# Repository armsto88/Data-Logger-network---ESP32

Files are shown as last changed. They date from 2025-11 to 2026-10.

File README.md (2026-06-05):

# ESP32 Sensor Network � Mothership + Nodes

An **ESP-NOW**�based environmental sensor network: field-deployed nodes collect data, a mothership hub aggregates and logs it, and an optional LTE backhaul uploads to the cloud.

---

## Repository Structure

```
mothership/           Mothership hub (ESP32-WROOM)
  docs/                 Power, wake, LTE, PCB design notes
  firmware/src/         Production firmware (main, BLE, ESP-NOW, SD, RTC)

node/                 Sensor nodes (ESP32-WROOM)
  docs/                 Hardware, sensors, ultrasonic design notes
  firmware/
    src/                Production firmware (main, drivers, sensors, storage, time)
    shared/             Shared protocol headers (protocol.h, sensors.h)
    tests/              Bring-up and validation sketches

docs/                 Shared/cross-system documentation
  concept_overview.md   System architecture and ESP-NOW messaging
  FIRMWARE_AND_HARDWARE_NOTES.md  Integration notes
  NATIVE_APP_*.md       App integration and data schemas
  MULTI_NODE_VALIDATION_*.md  Deployment validation
  archive/              Manuscript drafts and reference files

hardware/             PCB, CAD, simulation, and manufacturing assets
  ultrasonic_anemometer/  Ultrasonic wind sensor subproject

platformio.ini       Build configuration (all targets)
CONTRIBUTING.md      Repo organization and contribution rules
```

---

## Quick Links

- **Mothership docs:** [mothership/docs/README.md](mothership/docs/README.md)
- **Node docs:** [node/docs/README.md](node/docs/README.md)
- **Shared docs index:** [docs/README.md](docs/README.md)
- **Contribution guide:** [CONTRIBUTING.md](CONTRIBUTING.md)

---

## System Overview

### Mothership (ESP32-WROOM)

- Runs a Wi-Fi access point with a web UI dashboard
- Receives sensor data from nodes via ESP-NOW
- Logs all data to CSV on a microSD card
- Keeps time via a DS3231 RTC (the network time authority)
- Manages node discovery, pairing, deployment, and scheduling
- Power-gated design: DS3231 alarm or config button wakes the board; ESP32 latches power via `PWR_HOLD`
- Two power domains: `KEEP_ALIVE` (always-on, RTC + config latch) and `3V3_SYS` (switched, ESP32 + SD + logic)
- Optional LTE backhaul via SIMCom A7670G modem (UART2 + level shifters)
- CH340C USB-UART for programming and serial console

### Sensor Nodes (ESP32-WROOM)

- Sleep between measurement intervals (DS3231 Alarm 1 + FET power gate)
- Environmental sensors: SHT40 (temp/humidity), AS7343 (light spectrum), ADS1015 (soil probes)
- Ultrasonic anemometer subsystem: 40 kHz transducers, MT3608 22 V boost, TC4427 driver, TLV9062IDR RX amplifier
- I2C sensor mux via PCA9548A
- Transmit readings to the mothership via ESP-NOW
- Automatically request time sync when needed
- Resume operation after power cuts (NVS state + RTC coin cell)
- RUN/KILL hard switch for full power cut

### Communication

- **Data:** node -> mothership (`SENSOR_DATA` packets)
- **Control:** mothership -> node (`PAIR_NODE`, `DEPLOY_NODE`, `SET_SCHEDULE`, `UNPAIR_NODE`, `TIME_SYNC`)
- **Discovery:** nodes broadcast `DISCOVER_REQUEST`; mothership responds

---

## Building

The root `platformio.ini` defines all build targets. Build from the repo root:

```bash
# Mothership
pio run -e esp32s3

# Node main systems bring-up
pio run -e esp32wroom-v2-main-systems

# Individual bring-up tests
pio run -e esp32wroom-i2c-scan
pio run -e esp32wroom-ds3231-alarm-10s
pio run -e esp32wroom-sht40-as7343-mux
# ... see platformio.ini for all environments
```

---

## Key Design Documents

| Document | Location | Description |
|---|---|---|
| Power & Wake Architecture | [mothership/docs/MOTHERSHIP_POWER_AND_WAKE_DESIGN_NOTE.md](mothership/docs/MOTHERSHIP_POWER_AND_WAKE_DESIGN_NOTE.md) | Power gating, RTC wake, pin allocation |
| PCB Schematic Review | [mothership/docs/MOTHERSHIP_PCB_SCHEMATIC_REVIEW_2026-06-05.md](mothership/docs/MOTHERSHIP_PCB_SCHEMATIC_REVIEW_2026-06-05.md) | Consolidated pre-order review with critical checks |
| LTE Backhaul Concept | [mothership/docs/MOTHERSHIP_LTE_BACKHAUL_CONCEPT.md](mothership/docs/MOTHERSHIP_LTE_BACKHAUL_CONCEPT.md) | A7670G modem integration and upload workflow |
| Node Hardware Checklist | [node/docs/NODE_HARDWARE_V2_CHECKLIST.md](node/docs/NODE_HARDWARE_V2_CHECKLIST.md) | V2 hardware bring-up and validation |
| Node PCB Overview | [node/docs/NODE-PCB-OVERVIEW.md](node/docs/NODE-PCB-OVERVIEW.md) | Node PCB design summary and pin mapping |
| Local Storage Contract | [node/docs/NODE-LOCAL-STORAGE-CONTRACT-V1.md](node/docs/NODE-LOCAL-STORAGE-CONTRACT-V1.md) | Queue storage and data format specification |
| Concept Overview | [docs/concept_overview.md](docs/concept_overview.md) | High-level system architecture |

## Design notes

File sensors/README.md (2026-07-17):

# Sensor Calibration & Validation Documentation

This directory contains peer-review frameworks and calibration protocols for the FieldMesh data logger sensors, grounded in scientific literature on sensor accuracy, precision, and field validation.

## Documents

### 1. [CALIBRATION_VALIDATION_SCIENTIFIC_FOUNDATION.md](CALIBRATION_VALIDATION_SCIENTIFIC_FOUNDATION.md)
**Start here.** A survey of scientific principles for sensor calibration and validation.

**Covers:**
- Pre-deployment vs. post-deployment calibration strategies
- Accuracy vs. precision definitions
- Environmental sensor inter-comparison methods
- Sensor drift drivers (temperature, humidity, UV, chemistry, stress)
- In-situ recalibration algorithms for sensor networks
- Data quality & outlier detection
- Peer review checklist

**Key insight:** Laboratory calibration alone is insufficient. Field validation against reference standards is essential.

---

### 2. [SOIL_MOISTURE_CALIBRATION_PROTOCOL.md](SOIL_MOISTURE_CALIBRATION_PROTOCOL.md)
**For soil moisture sensors** (ADS1115 + capacitive probes).

**Phases:**
1. **Pre-deployment (lab):** Dry-down calibration curves for site-representative soil samples
2. **Field site survey:** Soil texture/density characterization; matching to lab curves
3. **On-site field calibration:** Gravimetric validation or reference sensor cross-check
4. **Drift monitoring:** Monthly checks; outlier filtering; temperature correction
5. **Publication:** Quality claims + supporting data

**Expected accuracy:** ±0.03–0.05 m³/m³ (3–5% VWC) with proper field calibration.

**Key finding from literature:** Field-calibrated sensors achieve **50% better accuracy** than lab-only calibration.

---

### 3. [SPECTRAL_SENSOR_CALIBRATION_PROTOCOL.md](as7341/SPECTRAL_SENSOR_CALIBRATION_PROTOCOL.md)
**For the AS7341 spectral sensor** (8 visible bands + Clear + NIR).

**Phases:**
1. **Dark current baseline:** Offset calibration across all 11 gain settings
2. **Linearity validation:** Test ADC response across full intensity range
3. **Gain validation:** Verify auto-gain algorithm maintains consistency
4. **Spectral response:** Color accuracy and cross-channel crosstalk
5. **Field deployment:** PAR proxy validation against calibrated reference
6. **Thermal stability:** Temperature coefficient measurement & correction
7. **Snapshot validation:** Rules for flagging saturated/invalid/low-signal data
8. **Multi-node cross-check:** Consistency across deployed units

**Expected accuracy:** PAR estimates ±100 µmol m⁻² s⁻¹ (R² >0.85 vs. reference meter).

---

## How to Use These Documents

### For Initial Deployment
1. Read **CALIBRATION_VALIDATION_SCIENTIFIC_FOUNDATION.md** (20 min)
2. Follow the appropriate sensor protocol:
   - Soil sensors → **SOIL_MOISTURE_CALIBRATION_PROTOCOL.md**
   - Spectral sensor → **SPECTRAL_SENSOR_CALIBRATION_PROTOCOL.md**
3. Use the **peer review checklists** at the end of each protocol

### For Data Quality Assurance
- Reference the **drift monitoring** and **outlier detection** sections during deployment
- Compare observed sensor behavior against expected performance ranges documented
- Re-calibrate if drift exceeds thresholds (typically 5% per 30 days)

### For Publishing or Sharing Data
- Fill in the **data reporting template** from the protocol you used
- Cite the scientific papers listed (links provided)
- Attach calibration curves, validation plots, and raw metadata

---

## Scientific Foundation & References

All protocols are based on peer-reviewed literature:

### General Calibration
- [Sensor Calibration Overview (ScienceDirect Topics)](https://www.sciencedirect.com/topics/earth-and-planetary-sciences/sensor-calibration)
- [Framework for Simulation of Sensor Networks — In Situ Calibration Algorithms (PMC)](https://pmc.ncbi.nlm.nih.gov/articles/PMC7472635/)
- [Self-Calibration Methods for Uncontrolled Environments (arXiv)](https://arxiv.org/pdf/1905.11060)

### Environmental Sensor Accuracy
- [EPA: Precision and Accuracy Study](https://www.epa.gov/sites/default/files/2014-08/documents/precisionandaccuracy.pdf)
- [Challenges and Opportunities in Calibrating Low-Cost Environmental Sensors (PMC)](https://pmc.ncbi.nlm.nih.gov/articles/PMC11175279/)
- [Low-Cost Aerosol Sensor Inter-comparison (PMC)](https://pmc.ncbi.nlm.nih.gov/articles/PMC5580827/)
- [Electrical Conductivity Sensor Accuracy Study (PMC)](https://pmc.ncbi.nlm.nih.gov/articles/PMC10159144/)

### Soil Moisture Sensors
- [Calibration and Field Validation of Smart Soil Moisture Monitoring (Harvard ADS)](https://ui.adsabs.harvard.edu/abs/2023EGUGA..2511699Y/abstract)
- [Laboratory Calibration and Field Validation — 5TE Sensor (PMC)](https://www.ncbi.nlm.nih.gov/pmc/articles/PMC6928628/)
- [Designing and Field Calibration of Low-Cost Microcontroller-Based Sensors (Nature Scientific Reports)](https://www.nature.com/articles/s41598-024-81288-z)
- [Low-Cost Capacitive Soil Moisture Sensors for Irrigation (MDPI)](https://www.mdpi.com/1424-8220/25/2/343)
- [Calibration and Validation of Soil Water Reflectometers (Wiley)](https://acsess.onlinelibrary.wiley.com/doi/full/10.1002/vzj2.20190)

### Spectral/Optical Sensors
- [Dynamic Validation of Calibration Accuracy — Multi-Sensor Systems (PMC)](https://pmc.ncbi.nlm.nih.gov/articles/PMC11207938/)

### Environmental Drift
- [Environmental Stressors Causing Calibration Drift (Clarity.io Blog)](https://www.clarity.io/blog/which-environmental-stressors-most-often-trigger-calibration-drift-and-necessitate-shorter-calibration-intervals)

---

## Quick Reference: Calibration Timeline

| When | Action | Sensor Type | Evidence |
|---|---|---|---|
| **Before deployment** | Lab dry-down calibration | Soil | Calibration curve + R² |
| **Field site prep** | Soil characterization | Soil | Texture, bulk density, organic matter |
| **Week 1–2** | Baseline reference check | All | First gravimetric / reference measurement |
| **Weekly** | Auto-validation | Spectral | PAR proxy vs. reference meter (if available) |
| **Monthly** | Drift assessment | All | Re-measure reference samples or co-located sensor |
| **Quarterly** | Re-calibrate if drift >5% | All | Update coefficients; recapture baseline |
| **End of season** | Final accuracy report | All | Compare all readings to reference; summarize performance |

---

## Compliance & Quality Flags

Every sensor reading should be assigned a **quality flag**:

```
[VALID]              — all checks passed, use with confidence
[UNVALIDATED]        — not yet checked against reference, provisional
[DRIFT_WARNING]      — drift detected but <10%; monitor closely
[OUT_OF_RANGE]       — value physically impossible; reject
[SATURATED]          — sensor maxed out (especially spectral); data unreliable
[LOW_SIGNAL]         — noise-dominated; low confidence
[RECALIBRATED]       — fresh calibration applied; baseline reset
[REFERENCE_MISMATCH] — doesn't match reference sensor; investigate
```

Include these flags in your data export so downstream analysis knows data provenance.

---

## Next Steps

1. **Soil moisture:** Complete Phase 1 (lab calibration) before field deployment. Plan Phase 3 (field validation) for first 2 weeks on site.

2. **Spectral sensor:** Phase 1–2 can happen in a lab or bright room. Phase 5 (field validation) requires 1–2 weeks of co-location with a PAR meter (borrow one if needed).

3. **Air temperature/humidity (SHT41):** Low-cost, already factory-calibrated to ±2–3%. Skip extensive re-calibration; just verify no physical damage to sensor package before deployment.

4. **Wind (reed anemometer):** Validate against weather station wind data if available. Anemometer accuracy typically ±5% (factory spec); field comparison is optional.

---

## Questions or Improvements?

These protocols are **living documents**. As you complete calibrations and field validation, update them with:
- Actual results (photos of calibration setups, plots)
- Lessons learned (unexpected sensor behaviors, drift patterns)
- Improvements to procedures (what worked, what didn't)

Share findings with other deployments and the broader FieldMesh community.

---

**Document version:** 1.0  
**Date created:** 2026-07-04  
**Author:** Claude Code (based on peer-reviewed scientific literature)  
**Next review:** After first field season data is collected

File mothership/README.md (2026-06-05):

# Mothership

ESP32-S3 mothership hub: Wi-Fi AP, SD logging, ESP-NOW coordination, RTC time sync, and LTE backhaul.

## Contents

- **docs/** — mothership-specific design notes
  - Power and wake architecture
  - LTE backhaul concept
  - PCB schematic review and reconciliation
  - MT3608 brownout analysis
- **firmware/src/** — production firmware source
  - `main.cpp` — entry point, web UI, ESP-NOW RX loop
  - `ble/` — BLE peripheral for mobile app comms
  - `comms/` — ESP-NOW manager (RX, time sync, node pairing)
  - `storage/` — SD card CSV logging
  - `system/` — compile-time config and pin definitions
  - `time/` — DS3231 RTC control

## Build

The mothership build target is defined in the root `platformio.ini`. Build from the repo root:

```bash
pio run -e mothership
```

## Related

- Shared docs: [docs/](../docs/)
- Node firmware and docs: [node/](../node/)
- Hardware assets: [hardware/](../hardware/)

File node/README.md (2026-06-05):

# Node

ESP32-C3 sensor nodes: sleep/wake, sensor read, ESP-NOW TX, RTC scheduling, local queue storage.

## Contents

- **docs/** — node-specific design notes
  - Hardware V2 checklist and PCB overview
  - Local storage contract
  - Sensor implementation notes (soil, SHT41, AS7343)
  - Ultrasonic anemometer design notes
  - Bring-up results
- **firmware/src/** — production firmware source
  - `main.cpp` — entry point, sleep/wake, sensor read, TX, sync
  - `drivers/` — ADS1115 ADC helper
  - `sensors/` — sensor drivers (SHT41, AS7343, soil, ultrasonic wind)
  - `storage/` — local NVS queue for readings
  - `time/` — DS3231 RTC wake scheduling
- **firmware/shared/** — shared protocol headers
  - `protocol.h` — ESP-NOW message formats and payloads
  - `sensors.h` — sensor ID and data format constants
- **firmware/tests/** — bring-up and validation sketches
  - Individual hardware test programs for each peripheral
  - V2 system validation tests
- **firmware/platformio.ini** — node build configuration

## Build

The node build target is defined in `node/firmware/platformio.ini`. Build from the repo root:

```bash
pio run -e sensor-node
```

## Related

- Shared docs: [docs/](../docs/)
- Mothership firmware and docs: [mothership/](../mothership/)
- Hardware assets: [hardware/](../hardware/)

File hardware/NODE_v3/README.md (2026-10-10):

# Node v3 hardware

This directory contains fabrication releases for the ESP32 Node v3 board.

## Releases

| Release | Contents | Review |
|---|---|---|
| `revisions/2026-10-09` | Field-proven EasyEDA Pro baseline, Gerbers, BOM, and pick-and-place data | [Ultrasonic and 22 V removal plan](revisions/2026-10-09/REVIEW.md) |
| Repository-root files dated `2026-06-28` | Earlier Gerber, BOM, and pick-and-place export retained for history | Not reviewed here |

The supplied source and manufacturing files in the dated revision were copied
without modification. The review records how to remove the ultrasonic TX/RX
and 22 V circuitry from a new working copy; it does not modify the archived,
field-proven baseline.

Do not overwrite the baseline project. After completing the removal, store the
new EasyEDA source and regenerated manufacturing outputs in a separate dated
revision and verify them against the removal checklist before fabrication.

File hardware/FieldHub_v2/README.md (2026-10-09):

# FieldHub v2 hardware

This directory contains the fabrication releases for the FieldHub/Hub v2 board.

## Releases

| Release | Contents | Review |
|---|---|---|
| `revisions/2026-10-08-r2` | Separate same-day revision 2: EasyEDA Pro project, Gerbers, BOM, and pick-and-place data | [Engineering review](revisions/2026-10-08-r2/REVIEW.md) |
| `revisions/2026-10-08` | EasyEDA Pro project, Gerbers, BOM, and pick-and-place data | [Engineering review](revisions/2026-10-08/REVIEW.md) |
| `revisions/2026-10-07` | EasyEDA Pro project, Gerbers, BOM, and pick-and-place data | [Engineering review](revisions/2026-10-07/REVIEW.md) |
| `revisions/2026-10-01` | EasyEDA Pro project, seven standalone schematic sheets, Gerbers, BOM, and pick-and-place data | [Engineering review](revisions/2026-10-01/REVIEW.md) |
| Repository-root files dated `2026-07-24` | Earlier fabrication export retained for history | Not reviewed here |

The supplied design and manufacturing files under each dated revision were
copied without modification; the engineering review was added in the repository.
The date-based directories keep each release separate and give future revisions
an unambiguous home.

Do not treat the presence of Gerbers as manufacturing approval. Read the release
review and close its blocking/high-priority findings before ordering boards.

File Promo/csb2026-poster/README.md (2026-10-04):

# CSB 2026 conference poster

This directory is the working home for the FieldMesh poster for the Conference on Solar Energy and Biodiversity 2026.

## Current direction

- **Title:** Monitoring the mosaic
- **Subtitle:** FieldMesh for fine-scale environmental monitoring in solar farms
- **Format:** A0 portrait, 841 × 1189 mm
**Core story:** research gap → practical design requirements → FieldMesh architecture → validation pathway → research and management use

The recommended design direction is in [POSTER_CONCEPT.md](POSTER_CONCEPT.md). Claims and their source status are tracked in [SOURCE_AUDIT.md](SOURCE_AUDIT.md).

## Files

- `master_reference.md` — content-preserving import of `C:\Users\thoma\Downloads\fieldmesh_csb2026_poster_master_reference.md`. Treat this as the canonical brief.
- `POSTER_CONCEPT.md` — first layout, narrative and visual direction.
- `SOURCE_AUDIT.md` — evidence map across the firmware, frontend and backend repositories.
- `assets/README.md` — asset checklist and naming convention.

## Source repositories

- Firmware, hardware and embedded documentation: this repository, `Data-Logger-network---ESP32`.
- Dashboard frontend, Supabase backend and cloud schema: `C:\Users\thoma\Documents\FieldMesh\FieldMeshDashboard`.
- Research origin: [A mosaic of microclimates: biodiversity outcomes and wildlife habitat potential in large-scale solar facilities](https://onlinelibrary.wiley.com/doi/10.1002/brv.70171).

## Conference requirements checked 2026-10-03

The official presenter guidance specifies A0 portrait, PDF delivery, no required template and onsite printing. Its poster section and “Important Dates” list **14 October 2026** as the deadline. The same page contains an apparently stale sentence requesting posters by 20 August; confirm by email if there is any doubt.

Official guidance: <https://www.conference-solar-biodiversity.org/abstract-guidelines-scolarships/guidelines-and-key-dates-for-oral-and-poster-presenters>

## Working rules

1. Keep the master reference intact; develop new copy in separate files.
2. Prefer the current source code over older design documents when they disagree.
3. Label implemented, bench-tested, field-validated and planned capabilities differently.
4. Do not describe the nodes as sleeping: they are hard-powered off between scheduled wakes.
5. Avoid absolute data-loss claims. Describe what happens after a reading is accepted into local storage and state the SD-card condition where relevant.
6. Keep the poster readable in two to three minutes; detailed engineering belongs in conversation or the QR-linked material.

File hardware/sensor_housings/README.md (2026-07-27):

# FieldMesh Sensor Housings

This folder contains the current standalone sensor-housing builds. Edit the
Python source files first, then regenerate the STL outputs.

## Toolchain

Geometry is script-generated, so a regenerated part is only reproducible
against a known generator version. These builds were produced with:

- **FreeCAD 1.0** (`freecadcmd`) — AS7341 PAR housing, node box sensor deck
- **Blender 5.1** — SHT40 Stevenson shield (mesh-derived)

The commands below assume `freecadcmd` and `blender` are on `PATH`. On Windows
they are typically at `C:\Program Files\FreeCAD 1.0\bin\freecadcmd.exe` and
`C:\Program Files\Blender Foundation\Blender 5.1\blender.exe`; invoke those
paths directly with `&` if they are not on `PATH`.

## Licensing

- **AS7341 PAR housing** and **node box sensor deck** are original work.
- **SHT40 Stevenson shield** is a derivative work under **CC BY 4.0**, built on
  published models by Thingiverse users commonslabgr and raingel. Its upstream
  source meshes, the upstream licence text, the full attribution chain, and the
  list of changes made are in `sht40_stevenson/upstream/` and
  `sht40_stevenson/LICENSE`. That attribution must travel with the part
  whenever it is redistributed or adapted.

## AS7341 PAR spectral housing

Source:

- `as7341_par/AS7341_PAR_STANDALONE.py`

Generated STL outputs:

- `as7341_par/stl/as7341_par_housing.stl`
- `as7341_par/stl/as7341_par_diffuser_retainer_ring.stl`

Current measured PCB assumptions:

- PCB length: `25.51 mm`
- PCB width: `11.00 mm`
- PCB hole centres: `19.30 mm`
- PCB post height: `15.00 mm`
- Diffuser diameter: `39.50 mm`
- Diffuser pocket diameter: `40.10 mm`
- Diffuser glue ledge width: `3.70 mm`
- Overall housing height: `48.50 mm`
- PCB screw top-access margin: `4.85 mm`
- PAR cable gland port: PG7 clearance, `13.00 mm`
- PAR cable gland centre height: `23.00 mm`
- PAR gland boss: `22.00 mm` OD, about `5.00 mm` effective panel thickness
- PAR gland faces: outside `22.00 mm` OD and inside `28.00 mm` OD, both running through the wall
- PAR internal PG7 flat: `28.00 mm` OD, `1.50 mm` projection into the housing
- PAR PG7 thread length: `7.80 mm`
- PAR internal PG7 locknut envelope: `17.70 mm` AF / `21.64 mm` swing diameter
- Retainer screws/inserts: M3 clearance screws into short M3 heat-set inserts
- Retainer screw PCD: `55.00 mm`
- Retainer lug overlap into body/ring: `4.00 mm`
- Retainer lug edge fillet radius: `0.55 mm`
- Retainer lug root bridges: disabled, using round ears with `11.00 mm` round necks
- Shared deck mount pitch: `64.00 mm`

Regenerate and preview/check:

```powershell
& "C:\Program Files\FreeCAD 1.0\bin\freecadcmd.exe" hardware\sensor_housings\as7341_par\AS7341_PAR_STANDALONE.py
```

The FreeCAD document shows the retainer above the housing for inspection; the
exported STL files are normalized individually to `Z=0` for slicing.

## SHT40 Stevenson shield

Source:

- `sht40_stevenson/modify_thingiverse_stevenson_sht40.py`
- `sht40_stevenson/SHT40_STEVENSON_BLENDER_STL_VIEWER.py`

Generated STL outputs:

- `sht40_stevenson/stl/sht40_stevenson_body_modified.stl`
- `sht40_stevenson/stl/sht40_pg7_retainer_flange.stl`
- `sht40_stevenson/stl/sht40_right_angle_bracket_adapter.stl`

Upstream source meshes (vendored, so no manual download is needed):

- `sht40_stevenson/upstream/stevenson_cap.stl` — the mesh the shield body is built from
- `sht40_stevenson/upstream/stevenson_base.stl` — reference only; not used in the normal two-piece build
- `sht40_stevenson/upstream/LICENSE.txt`, `README.txt` — upstream author's text, reproduced verbatim

The body starts from the upstream mini Stevenson shield STL and is modified in
Blender so the mesh-derived design remains repeatable. See
`sht40_stevenson/LICENSE` for the attribution chain and the list of changes.

Current measured probe/gland assumptions:

- Probe length from flange seat: `52.0 mm`
- Through-flange section diameter: `12.4 mm`
- Thread length through flange: `15.7 mm`
- Under-flange nut width across flats: `17.6 mm`
- Top clamp nut width across flats: `17.2 mm`
- Generated body/collar clearance bore: `21.52 mm`
- Generated flange through-hole: `13.00 mm`

The PG7/probe flange is a plain clamp plate, not a hex nut trap. Tighten the
probe/gland nuts onto the loose flange first. For right-angle mounting, place
the optional bracket adapter between the shield collar and the probe flange,
then use longer screws through the flange and adapter into the shield inserts.
The adapter and shield collar bores provide free clearance for the under-flange
nut.

Preview in Blender without writing STL files:

```powershell
blender --python hardware\sensor_housings\sht40_stevenson\modify_thingiverse_stevenson_sht40.py
```

Regenerate STL outputs only after the Blender preview looks right:

```powershell
blender --background --python hardware\sensor_housings\sht40_stevenson\modify_thingiverse_stevenson_sht40.py -- --export-stl
```

Both commands read the vendored meshes in `sht40_stevenson/upstream/` by
default; pass `-- --source-dir <path>` only to point at a different copy.
Exporting also writes `ATTRIBUTION.txt` alongside the STLs — keep it with them.

Open the generated STLs in a FreeCAD document:

```powershell
freecadcmd hardware\sensor_housings\sht40_stevenson\SHT40_STEVENSON_BLENDER_STL_VIEWER.py
```

## Node box sensor deck

Source:

- `node_box_sensor_deck/NODE_BOX_SENSOR_DECK.py`

Generated STL output:

- `node_box_sensor_deck/stl/node_box_sensor_deck.stl`

This deck is the shared adapter for the AS7341 PAR housing and the SHT40 shield.
Both use a 64 mm two-hole M3 mounting interface. The SHT40 station is rotated
onto the Y axis so its right-angle bracket can stay on the X side.
All housing/deck heat-set locations now target short M3/Voron-style inserts
with `4.4 mm` printed bores.

Regenerate and preview/check:

```powershell
& "C:\Program Files\FreeCAD 1.0\bin\freecadcmd.exe" hardware\sensor_housings\node_box_sensor_deck\NODE_BOX_SENSOR_DECK.py
```

The node-box lid spacing is still screenshot-derived. Verify the 110 x 122 mm
box fixing pattern on the physical enclosure before final drilling or printing.

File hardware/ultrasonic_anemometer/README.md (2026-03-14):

# Ultrasonic Anemometer Workspace

This folder contains all assets related to the ultrasonic anemometer program.

## Structure

- `docs/` - design and analysis documentation
- `firmware/` - ultrasonic node and mothership firmware prototypes
- `FreeCAD/` - CAD models and FreeCAD macros
- `hardware/` - PCB project files, fabrication outputs, and archived revisions
- `mechanical/` - printable geometry (`scad`, `stl`)
- `sim/` - OpenFOAM simulation cases and matrix runs

## Notes

- Active PCB project lives in `hardware/easyeda/` with `hardware/UltraSonic_Anemometer_HW.eprj`.
- Fabrication outputs are grouped under `hardware/fabrication/`.
- Old design snapshots are grouped under `hardware/archive/`.

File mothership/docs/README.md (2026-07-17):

# Mothership Documentation

**Last reviewed:** 2026-07-17

Design, bring-up, implementation, and review documents for the ESP32-WROOM mothership hub.

## Firmware architecture and implementation

- [FIELDMESH_OTA_FIRMWARE_UPDATE_PLAN.md](FIELDMESH_OTA_FIRMWARE_UPDATE_PLAN.md) - detailed signed OTA and backend-queued control plan, including local/dashboard state mirroring and mothership-to-node distribution (see §0 for build/proven status).
- [MOTHERSHIP_STATUS_REPORTING_PLAN.md](MOTHERSHIP_STATUS_REPORTING_PLAN.md) - tiered plan to report firmware identity, OTA state, control revision, and per-node firmware/desired-vs-applied into the cloud upload payload.
- [MOTHERSHIP_V1_FIRMWARE_PLAN.md](MOTHERSHIP_V1_FIRMWARE_PLAN.md) - wake-gated firmware architecture.
- [MOTHERSHIP_V1_DEPLOYMENT_UI_PLAN.md](MOTHERSHIP_V1_DEPLOYMENT_UI_PLAN.md) - deployment UI behaviour and state plan.
- [MOTHERSHIP_V2_ON_DEVICE_UI_UPGRADE_PLAN.md](MOTHERSHIP_V2_ON_DEVICE_UI_UPGRADE_PLAN.md) - current on-device UI upgrade plan.
- [MOTHERSHIP_V1_MODEM_UPLOAD_PLAN.md](MOTHERSHIP_V1_MODEM_UPLOAD_PLAN.md) - modem upload implementation plan.
- [MOTHERSHIP_V1_ROBUSTNESS_FIX_PLAN.md](MOTHERSHIP_V1_ROBUSTNESS_FIX_PLAN.md) - reliability fixes, acceptance plan, and the dated 2026-06-22 execution record consolidated on 2026-07-17.

## Bring-up and LTE

- [MOTHERSHIP_V1_BRINGUP_RESULTS_2026-06-19.md](MOTHERSHIP_V1_BRINGUP_RESULTS_2026-06-19.md) - hardware bring-up evidence.
- [MOTHERSHIP_LTE_BACKHAUL_CONCEPT.md](MOTHERSHIP_LTE_BACKHAUL_CONCEPT.md) - LTE hardware and backhaul strategy.
- [MOTHERSHIP_A7670G_MODEM_BRINGUP_NOTES.md](MOTHERSHIP_A7670G_MODEM_BRINGUP_NOTES.md) - A7670G power, UART, SIM, RF, and firmware bring-up.

## PCB and power

- [MOTHERSHIP_POWER_AND_WAKE_DESIGN_NOTE.md](MOTHERSHIP_POWER_AND_WAKE_DESIGN_NOTE.md) - power architecture, RTC wake cycles, boost converter, and pins.
- [MOTHERSHIP_PCB_SCHEMATIC_REVIEW_2026-06-05.md](MOTHERSHIP_PCB_SCHEMATIC_REVIEW_2026-06-05.md) - dated schematic review.
- [MOTHERSHIP_PCB_SCHEMATIC_RECONCILIATION.md](MOTHERSHIP_PCB_SCHEMATIC_RECONCILIATION.md) - design-note and schematic signal reconciliation.
- [MOTHERSHIP_PCB_PREORDER_CHECKS.md](MOTHERSHIP_PCB_PREORDER_CHECKS.md) - manufacturing/preorder gate extracted from the review.
- [MT3608_BROWNOUT_DESIGN_NOTE.md](MT3608_BROWNOUT_DESIGN_NOTE.md) - boost-converter brownout analysis.

Point-in-time reviews, reconciliations, and preorder gates remain separate because they record different dates and decision stages.

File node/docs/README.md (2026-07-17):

# Node Documentation

**Last reviewed:** 2026-07-17

Design notes, hardware checklists, sensor implementation records, and bring-up results for the ESP32-WROOM sensor nodes.

## Hardware and bring-up

- [NODE_HARDWARE_V2_CHECKLIST.md](NODE_HARDWARE_V2_CHECKLIST.md) - V2 hardware validation checklist.
- [NODE-PCB-OVERVIEW.md](NODE-PCB-OVERVIEW.md) - PCB architecture and pin mapping.
- [Node V2 bring-up results](../firmware/tests/NODE_V2_BRINGUP_RESULTS.md) - canonical V2 test record; the former one-line pointer in this folder was removed on 2026-07-17.
- [Node V3 bring-up results](../firmware/tests/NODE_V3_BRINGUP_RESULTS.md) - canonical V3 test record.
- [NODE_V3_OVERVIEW.md](NODE_V3_OVERVIEW.md) - complete V3 board overview.
- [NODE_V3_22V_BOOST_UPDATE.md](NODE_V3_22V_BOOST_UPDATE.md) - V3 22 V boost changes.
- [NODE_V3_ULTRASONIC_CHANGES_BRINGUP_FIRMWARE_GUIDE_2026-06-12.md](NODE_V3_ULTRASONIC_CHANGES_BRINGUP_FIRMWARE_GUIDE_2026-06-12.md) - V3 design changes and production firmware guidance.
- [NODE_V4_ULTRASONIC_REDESIGN_NOTES.md](NODE_V4_ULTRASONIC_REDESIGN_NOTES.md) - V4 shared bidirectional transducer redesign.

## Storage and robustness

- [NODE-LOCAL-STORAGE-CONTRACT-V1.md](NODE-LOCAL-STORAGE-CONTRACT-V1.md) - queue invariants, recovery, capacity, and tests.
- [NODE_ROBUSTNESS_FIX_PROMPTS.md](NODE_ROBUSTNESS_FIX_PROMPTS.md) - historical task-level robustness instructions retained for traceability.

## Sensors

- [SENSOR_AND_CSV_BRINGUP.md](SENSOR_AND_CSV_BRINGUP.md) - sensor initialisation and CSV bring-up.
- [CWT_TH-A_SOIL_SENSOR_IMPLEMENTATION_NOTES.md](CWT_TH-A_SOIL_SENSOR_IMPLEMENTATION_NOTES.md) - soil sensor driver implementation.
- [shared sensor-package checklist](../../docs/ADDING_A_NEW_SENSOR_CHECKLIST.md) - required end-to-end integration checks.

## Ultrasonic anemometer

- [ultrasonic_anemometer_function_note.md](ultrasonic_anemometer_function_note.md) - hardware/firmware function specification.
- [ULTRASONIC_ANEMOMETER_WORK_PLAN.md](ULTRASONIC_ANEMOMETER_WORK_PLAN.md) - development and validation plan.
- [ultrasonic_circuit_v2_design_advice.md](ultrasonic_circuit_v2_design_advice.md) - V2 circuit recommendations.
- [ULTRASONIC_NOISE_ANALYSIS_2026-04-11.md](ULTRASONIC_NOISE_ANALYSIS_2026-04-11.md) - dated signal/noise findings.
- [NODE_V3_ULTRASONIC_CHECKLIST.md](NODE_V3_ULTRASONIC_CHECKLIST.md) - V3 electrical and acoustic validation.

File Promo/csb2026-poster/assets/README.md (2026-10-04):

# Poster assets

Place approved, poster-ready assets in this directory. Keep raw/source material elsewhere and export only the selected high-resolution versions here.

## Naming convention

`<category>_<subject>_<view-or-state>_v<nn>.<ext>`

Examples:

- `hardware_node_v3_front_v01.png`
- `hardware_fieldhub_v2_front_v01.png`
- `ui_dashboard_overview_v01.png`
- `ui_fieldhub_pairing_v01.png`
- `diagram_architecture_v01.svg`
- `diagram_deployment_mosaic_v01.svg`

## Needed

- [ ] node hardware photo, clean background
- [ ] FieldHub hardware photo, clean background
- [ ] current dashboard overview screenshot
- [ ] current local setup/pairing screenshot
- [ ] architecture diagram
- [ ] hypothetical deployment illustration
- [ ] calibration/reference photograph
- [ ] FieldMesh logo or text lockup
- [ ] QR code after the destination is locked

## Export guidance

- Prefer SVG or PDF for diagrams and logos.
- Use PNG or TIFF for screenshots and photographs; avoid JPEG recompression where practical.
- At final placed size, raster assets should normally be at least 150 dpi and ideally 200–300 dpi.
- Remove private project names, access keys, precise site coordinates and other sensitive data from screenshots.
- If a screenshot uses synthetic data, label it “demonstration data” in the figure caption.

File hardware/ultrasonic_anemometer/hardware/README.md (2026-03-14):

# PCB Files and Manufacturing Artifacts

## Active Design

- `UltraSonic_Anemometer_HW.eprj`
- `easyeda/`

## Fabrication

- `fabrication/gerbers/` - unpacked gerber output
- `fabrication/jlcpcb_fab/` - JLCPCB submission bundle
- `fabrication/gerber_releases/` - archived gerber zip releases

## References

- `references/DXF_PCB1_2026-03-04_AutoCAD2007.dxf`
- `references/esp32_devkitc_v4-sch.pdf`

## Archive

- `archive/UltraSonic_Anemometer_HW_backup/`

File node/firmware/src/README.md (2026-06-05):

# Sensor Node Source Layout

- `main.cpp`: node lifecycle, pairing/deploy state, ESPNOW loop, and wake logic.
- `drivers/`: low-level sensor interface drivers (e.g., ADS1115).
- `sensors/`: sensor backends and calibration helpers.
- `time/`: DS3231 wake interval/alarm helper logic.

Shared interfaces are in `../shared/` (for example `protocol.h` and `sensors.h`).

## Build Target

- Project file: `platformio.ini` (repo root)
- Environment: `esp32wroom-v2-main-systems`
- Board: `esp32dev` (ESP32-WROOM)

## Build From Repo Root

```powershell
pio run -e esp32wroom-v2-main-systems
```

## Individual Bring-up Tests

See `platformio.ini` for all `esp32wroom-*` environments. Common ones:

```powershell
pio run -e esp32wroom-i2c-scan
pio run -e esp32wroom-ds3231-alarm-10s
pio run -e esp32wroom-sht40-as7343-mux
```

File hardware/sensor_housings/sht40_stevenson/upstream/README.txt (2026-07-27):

Stevenson Shield (mini) by commonslabgr on Thingiverse: https://www.thingiverse.com/thing:4915068

Summary:
This is a remix of the https://www.thingiverse.com/thing:3486326 Stevenson shield.We needed a small shield that can stand abuse and fit inside it a small case with a BME280 sensor for our Troglometer project.We needed a way to have easy assembly and ease of removing the sensor to be replaced so we we did a small slit at the base to accommodate this featureCan be fitted on a surface with screws but also has a slit to secure a cable tie.It has been printed successfully with PLA economy. The editing is done using Blender 3D

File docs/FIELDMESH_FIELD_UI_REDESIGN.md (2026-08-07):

# fieldMesh Field UI Redesign — Captive Portal (192.168.4.1)

**Date:** 2026-06-26
**Status:** Design document (no code changes)
**Project:** fieldMesh — ESP32 environmental sensor network
**Scope:** Mothership WiFi AP config portal served from ESP32 flash at `192.168.4.1`
**Companion docs:**
- `docs/FIELDMESH_DASHBOARD_DESIGN.md` — cloud dashboard visual reference
- `docs/FIELDMESH_USER_ONBOARDING_BRIEF.md` — provisioning flow, QR/API-key design
- `docs/FIELDMESH_CLOUD_UPLOAD_PROTOCOL.md` — JSON upload payload
- `mothership/firmware/v2/src/config/config_server.cpp` — current Field UI implementation

---

## 1. Executive Summary

The mothership's captive portal is the only on-device interface a field user sees. Today it speaks in developer language — "nodes", "deploy/paired/unpaired", "sync window", "wake interval", "ESP-NOW", "Flash/LittleFS/NVS". The target users are ecologists, town planners, site valuers, and subdivision planners. They do not need to know that the radio protocol is ESP-NOW or that logs live in LittleFS. They need to know: *is my network recording, are my stations healthy, is data reaching the cloud.*

This document redesigns the Field UI into **four plain-English pages** — Hub Overview, Stations, Settings, Data Export — using the sage green / terracotta / warm stone palette already applied to the cloud dashboard. The hierarchy is renamed to **Hub → Stations → Sensors**. All mechanism details (ESP-NOW, MAC addresses, flash filesystems, modem AT commands, phase alignment, config versions, firmware build strings) are hidden from the default view and moved to a collapsed Advanced/About section.

**Confirmed decisions:**
- Four pages maximum, mobile-first, card-based layout.
- Terminology mapping in §3 is binding for all user-visible strings.
- Existing async-form pattern and captive portal redirect are preserved.
- CSS stays inline in `PROGMEM`; no external resources, no internet.

**Open questions:** see §12.

---

## 2. User Personas and Mental Models

### 2.1 Personas

| Persona | Role | What they do at the portal | What they never need to see |
|---|---|---|---|
| **Ecologist** | Deploys stations, checks data health | Start monitoring, check station batteries, export CSV | ESP-NOW, MAC, flash, config versions |
| **Town planner** | Occasional check-in during a study | Connect WiFi, see green status, leave | Sync anchors, retry counts, modem AT |
| **Site valuer** | One-off deployment, low technical confidence | Guided first-time setup, name stations, start | LittleFS, NVS, firmware build strings |

### 2.2 Mental model

The user thinks in three layers:

1. **The Hub** — "the box I connect my phone to." It collects data and uploads it.
2. **Stations** — "the sensor boxes out in the field." Each has a name, a battery, and a set of sensors.
3. **Sensors** — "what each station measures." Air temp, soil moisture, wind, etc.

The user does **not** think in terms of radio protocols, filesystems, or config snapshots. The UI must map every internal concept onto these three layers or hide it entirely.

---

## 3. Terminology Mapping Table

This table is **binding** for all user-visible strings in the Field UI. The right-hand column must never appear in the default view.

| Internal / developer term | User-facing term | Notes |
|---|---|---|
| Node | **Station** | Used everywhere a card, heading, or button refers to a remote device |
| Mothership | **Hub** | The device the user is connected to |
| Deploy | **Activate** | The act of starting a station monitoring |
| Paired | **Connected** | Station is known to the Hub but not yet activated |
| Unpaired | **New** | Station has been discovered but not yet added |
| Sync window | **Collection round** | The window when stations send data to the Hub |
| Wake interval | **Recording interval** | How often each station wakes to measure |
| Sync interval | **Upload interval** | How often the Hub sends data to the cloud |
| Sync & Power Down | **Start Monitoring** | The button that closes the portal and begins the field cycle |
| Flash / LittleFS / NVS | **Storage** | Any reference to on-device persistence |
| ESP-NOW | *(hidden entirely)* | Never shown; the radio is not a user concept |
| MAC address | *(hidden in daily-use views; **prominent in the Connect flow**)* | Collapsed About/Debug view on Home and elsewhere — but the FieldHub MAC is the identifier the dashboard asks for when registering a hub, so `/provision` step 1 and the Settings "FieldHub identity" section show it large, monospaced, with a copy control. Hiding it there was a real onboarding failure: operators could not find the one value they needed first. |
| Config version | *(hidden)* | Never shown |
| Firmware build string | *(Advanced/About only)* | Moved to collapsed section |
| Cursor offset / retry count | **"Last upload: success / failed"** | Show outcome, not mechanism |
| CCHSEND / modem AT commands | *(hidden entirely)* | Never shown |
| Phase alignment / sync anchor | *(hidden entirely)* | Never shown |
| Discover Nodes | **Find New Stations** | The scan button |
| Node manager | **Stations** | The list page |
| LTE Upload Settings | **Settings** (cloud section) | Folded into the single Settings page |

---

## 4. Page-by-Page Design with Wireframes

The portal has four pages. Routes are restructured but the captive portal redirect and async-form pattern are preserved.

### Route map (proposed)

| Current route | Proposed route | Page |
|---|---|---|
| `/` (handleRoot) | `/` | Hub Overview |
| `/nodes` (handleNodesPage) | `/stations` | Stations list |
| `/node-config` (handleNodeConfigForm) | `/station?id=...` | Station detail |
| `/upload` (handleUploadSettings) | `/settings` | Settings |
| `/download-csv` (handleDownloadCSV) | `/export` | Data Export |
| `/shutdown` (handleShutdown) | `/start` (POST) | Start Monitoring confirmation |
| `/discover-nodes` | `/find-stations` (POST) | Find New Stations action |
| `/set-wake-interval` | `/set-recording-interval` (POST) | Settings action |
| `/set-transmission` | `/save-settings` (POST) | Settings action |

> **Open question:** whether to keep old routes as redirects for backwards compatibility during migration (see §11).

---

### Page 1 — Hub Overview (`/`)

**Purpose:** Landing page. At-a-glance answer to "is everything working?"

**Layout (ASCII wireframe, 600px mobile container):**

```
┌─────────────────────────────────────┐
│         fieldMesh                   │  ← header, sage accent
│         Hub Overview                │
├─────────────────────────────────────┤
│  Hub time        14:32  26 Jun 2026 │  ← top time bar (warm stone)
├─────────────────────────────────────┤
│  ┌──────────┐ ┌──────────┐          │
│  │ Hub      │ │ Storage  │          │  ← status cards row
│  │ battery  │ │  42% used│          │
│  │  3.9V OK │ │ 1.2 MB   │          │
│  └──────────┘ └──────────┘          │
├─────────────────────────────────────┤
│  STATIONS                           │
│  ┌─────┐ ┌─────┐ ┌─────┐            │
│  │  4  │ │  3  │ │  1  │            │  ← KPI stat row
│  │Active│ │Conn-│ │ New │           │
│  │      │ │ected│ │     │           │
│  └─────┘ └─────┘ └─────┘            │
├─────────────────────────────────────┤
│  COLLECTION SCHEDULE                │
│  Recording every   10 min           │
│  Upload every      1 hour           │
│  Next collection   14:40 today      │
├─────────────────────────────────────┤
│  CLOUD UPLOAD                       │
│  ● Connected                        │  ← sage dot if connected
│  Last upload   14:05  · 128 readings│
├─────────────────────────────────────┤
│  ┌─────────────────────────────┐    │
│  │  Manage Stations          > │    │  ← big touch button (sage)
│  └─────────────────────────────┘    │
│  ┌─────────────────────────────┐    │
│  │  Settings                  > │    │
│  └─────────────────────────────┘    │
│  ┌─────────────────────────────┐    │
│  │  Export Data               > │    │
│  └─────────────────────────────┘    │
│  ┌─────────────────────────────┐    │
│  │  ▶  Start Monitoring        │    │  ← primary CTA (sage solid)
│  └─────────────────────────────┘    │
├─────────────────────────────────────┤
│  ▸ About / Advanced                 │  ← collapsed, see §8
└─────────────────────────────────────┘
```

**Content rules:**
- **Hub battery:** voltage + chip (`3.9V OK` / `3.4V Low`). Chip colour: sage ≥3.9V, terracotta 3.5–3.9V, red <3.5V. *(Open question: Hub battery voltage is not currently in `buildStatusJson()` — see §12.)*
- **Storage usage:** percentage + bytes used, labelled "Storage" never "Flash".
- **Station count:** three KPI tiles — Active (sage), Connected (terracotta), New (muted red). Maps to current `deployed / paired / unpaired`.
- **Collection schedule:** "Recording every X min", "Upload every Y min", "Next collection: HH:MM today". Uses `gWakeIntervalMin`, `gSyncIntervalMin`, `computeNextSyncIsoLocal()`.
- **Cloud upload status:** sage dot + "Connected" if `tx.enabled` and last upload recent; "Not set up" if no API key; "Last upload failed" if retry count high. Show "X readings sent" from `cursor.rowsUploaded`.
- **Navigation buttons:** Manage Stations → `/stations`; Settings → `/settings`; Export Data → `/export`; Start Monitoring → POST `/start`.
- **About / Advanced:** collapsed `<details>`. Contains device ID, firmware version, build string, SSID, MAC, IP. See §8.

---

### Page 2 — Stations (`/stations`)

**Purpose:** List every station as a card. Tap a card for detail.

**Wireframe:**

```
┌─────────────────────────────────────┐
│  ‹ Back        Stations    Refresh  │
├─────────────────────────────────────┤
│  ┌─────────────────────────────┐    │
│  │  North Hedge 01             │    │
│  │  ● Active    🔋 4.1V         │    │  ← status chip + battery chip
│  │  6 sensors · 10 min          │    │
│  │  Last reading 14:32 · 22.1°C │    │
│  └─────────────────────────────┘    │
│  ┌─────────────────────────────┐    │
│  │  South Fence 02             │    │
│  │  ● Connected  🔋 3.6V        │    │
│  │  4 sensors · 10 min          │    │
│  │  Last seen 14:20             │    │
│  └─────────────────────────────┘    │
│  ┌─────────────────────────────┐    │
│  │  ENV_94E38C                 │    │
│  │  ● New       🔋 n/a          │    │  ← muted red chip
│  │  Not yet activated           │    │
│  └─────────────────────────────┘    │
│  ┌─────────────────────────────┐    │
│  │  +  Add New Station          │    │  ← guided flow button
│  └─────────────────────────────┘    │
└─────────────────────────────────────┘
```

**Station card fields:**
- **Name** (or `ENV_xxxxxx` if unnamed) — large, bold.
- **Status chip:** Active (sage) / Connected (terracotta) / New (muted red). Maps to `DEPLOYED / PAIRED / UNPAIRED`.
- **Battery chip:** voltage + colour band. `n/a` if `isnan(lastReportedBatV)`.
- **Sensor count:** "N sensors" derived from `sensorPresent` bitmask. *(Open question: `NodeInfo` has no `sensorPresent` — see §12.)*
- **Recording interval:** "10 min" from `wakeIntervalMin`.
- **Last reading summary:** "Last reading 14:32 · 22.1°C" — timestamp + one headline value (air temp if present, else first available). If no reading yet: "Last seen 14:20" or "Not yet activated".

**Add New Station button** opens a guided instructions panel (not a separate page):

```
┌─────────────────────────────────────┐
│  Add a New Station                  │
├─────────────────────────────────────┤
│  1. Press the pair button on the    │
│     station (hold 3 seconds).       │
│  2. Wait for the green light.       │
│  3. Tap "Find New Stations" below.  │
│                                     │
│  [ Find New Stations ]              │  ← POST /find-stations
│                                     │
│  The station will appear in the     │
│  list as "New". Tap it to activate  │
│  and give it a name.                │
└─────────────────────────────────────┘
```

---

### Page 2b — Station Detail (`/station?id=...`)

**Purpose:** One station, full detail. Edit name/notes, view sensors, stop or remove.

**Wireframe:**

```
┌─────────────────────────────────────┐
│  ‹ Back   North Hedge 01   Refresh  │
├─────────────────────────────────────┤
│  ● Active    🔋 4.1V OK              │
│  Recording every 10 min             │
│  Last reading 14:32 today           │
├─────────────────────────────────────┤
│  SENSORS                            │
│  ✓ Air temperature     22.1 °C      │
│  ✓ Air humidity        48.8 %       │
│  ✓ Battery             4.1 V        │
│  ✓ Spectral (8 ch)     see below    │
│  ✓ Wind speed          3.5 m/s      │
│  ✓ Wind direction      180°         │
│  — Soil moisture 1    (not fitted)  │
│  — Soil temperature 1 (not fitted)  │
│  — Soil moisture 2    (not fitted)  │
│  — Soil temperature 2 (not fitted)  │
│  — Aux 1              (not fitted)  │
│  — Aux 2              (not fitted)  │
├─────────────────────────────────────┤
│  Spectral detail (tap to expand)    │
│   415nm  1.0   445nm  3.0           │
│   480nm  2.0   515nm  4.0           │
│   555nm  9.0   590nm  9.0           │
│   630nm  6.0   680nm 10.0           │
├─────────────────────────────────────┤
│  NAME & NOTES                       │
│  Name   [ North Hedge 01      ]     │
│  Notes  [ Sheltered north face  ]   │
├─────────────────────────────────────┤
│  ┌─────────────────────────────┐    │
│  │  Save Changes               │    │
│  └─────────────────────────────┘    │
│  ┌─────────────────────────────┐    │
│  │  ⏸ Stop Monitoring          │    │  ← terracotta, confirm first
│  └─────────────────────────────┘    │
│  ┌─────────────────────────────┐    │
│  │  ✕ Remove Station           │    │  ← red, confirm first
│  └─────────────────────────────┘    │
└─────────────────────────────────────┘
```

**Sensor list rules:**
- Every possible sensor in the standard profile is listed (see §5).
- `✓` = present (from `sensorPresent` bitmask), value shown from last snapshot.
- `—` = absent, labelled "(not fitted)".
- Spectral is shown as a single row "Spectral (8 ch)" with an expandable detail block.
- Values use the units from `FIELDMESH_DASHBOARD_DESIGN.md` sensor metadata.

**Stop Monitoring** = revert from Active to Connected (current `handleRevertNode`). Confirmation prompt: "Stop monitoring this station? It will stop recording but stay connected to the Hub."

**Remove Station** = unpair (current unpair flow). Confirmation prompt: "Remove this station? You'll need to re-add it with the pair button if you want it back."

---

### Page 3 — Settings (`/settings`)

**Purpose:** All configuration in one place. Plain English. Advanced collapsed.

> **Amended.** Cloud connection is **not** configured on this page. `/provision`
> owns registration and connection end-to-end; Settings links to it with a single
> primary "Connect to FieldMesh" action and otherwise only *reports* what is
> configured. The wireframe below predates that split — read its CLOUD CONNECTION
> block as the connected-state summary, not as an entry form. Settings also now
> carries a **FieldHub identity** section (MAC + copy control, outside the
> FieldMesh gate so an unprovisioned hub can see it) and a **Cellular** section
> for the SIM APN. "Re-run full setup" sits at the bottom of the page as a
> secondary action — it used to sit at the top beside a separate "connect field
> hub" block that launched the same wizard, which read as two different jobs.

**Wireframe:**

```
┌─────────────────────────────────────┐
│  ‹ Back        Settings             │
├─────────────────────────────────────┤
│  RECORDING INTERVAL                 │
│  How often each station measures.   │
│  [ 1 min ][ 5 min ][ 10 min ]       │  ← preset buttons
│  [ 30 min ]                         │
│  Selected: 10 min                   │
├─────────────────────────────────────┤
│  UPLOAD INTERVAL                    │
│  How often the Hub sends data to    │
│  the cloud.                         │
│  [ Every collection ]               │
│  [ 18 min ][ 1 hour ][ Daily ]      │
│  Selected: 1 hour                   │
├─────────────────────────────────────┤
│  CLOUD CONNECTION                   │
│  API Key                            │
│  [ fm_xxxxxxxx                ]     │
│  (QR paste field REMOVED — see      │
│   supersession note below)          │
│  Endpoint (set by provisioning)     │
│  https://....supabase.co/...        │
│  FieldMesh configured               │
│  Last successful upload: 14:05      │
├─────────────────────────────────────┤
│  ▸ Advanced settings                │  ← collapsed <details>
│    Min battery:    3500 mV          │
│    Max bytes/session: 50000         │
│    Max retries:    3                │
│    Allow manual upload now          │
├─────────────────────────────────────┤
│  ┌─────────────────────────────┐    │
│  │  Save & Start Monitoring    │    │  ← primary CTA (sage)
│  └─────────────────────────────┘    │
└─────────────────────────────────────┘
```

**Preset buttons** replace the current `<select>` dropdown for recording interval. The selected preset is highlighted with a sage inset shadow (reuse `.action-choice` pattern from `COMMON_CSS`).

**Upload interval presets:**
- "Every collection" = `uploadIntervalMin = 0`
- "18 min" = `18`
- "1 hour" = `60`
- "Daily" = `1440` (or daily-mode flag)

**Cloud connection** folds the current `handleUploadSettings` form fields:
- API Key field (existing `api_key`).
- Endpoint shown read-only (existing behaviour).
- Status: **two separate lines**, never merged — "FieldMesh configured" (approved
  endpoint + stored key) and "Last successful upload: {time}, or never".

> **Superseded — `url|key` QR paste field.** This section previously specified a
> `qr_string` field that split on `|` to set the endpoint and key at once. Both
> the field and its parser are **removed**. The reason matters more than the
> replacement: `url|key` wrote an arbitrary, request-supplied endpoint into
> storage, bypassing `hwEndpointAllowed()`. A single POST could redirect a hub's
> uploads — and therefore its device key — to any host. The endpoint is now
> written only by `/provision-apply`, from a validated `FM1` payload. Do not
> reintroduce any request-controlled endpoint writer here.

> **Superseded — "Connected" status.** The single-line "Connected · last upload"
> status is gone. The firmware never verified a connection: nothing contacts the
> endpoint until the next sync, and `lastUploadUnix` is not scoped to the current
> endpoint or key, so it can describe an upload made before a key rotation or
> while custom HTTPS was active. "Connected" would need a configuration
> generation recorded against the last authenticated upload — that does not exist
> yet, so the UI states the two facts it can actually check, separately.

**Advanced settings** (collapsed `<details>`, same pattern as current):
- Min battery (mV)
- Max bytes per session
- Max retries per window
- Allow manual upload checkbox
- Auth token, site ID, deployment ID (kept for backwards compat, labelled "Legacy fields — leave blank unless advised")

**Save & Start Monitoring** = save settings then POST `/start` (replaces "Sync & Power Down").

---

### Page 4 — Data Export (`/export`)

**Purpose:** CSV download, kept simple. Existing `/download-csv` feature.

**Wireframe:**

```
┌─────────────────────────────────────┐
│  ‹ Back       Data Export           │
├─────────────────────────────────────┤
│  STORAGE                            │
│  1,284 records                      │
│  From 2026-06-20  to 2026-06-26     │
│  CSV size: 1.2 MB                   │
│  Storage used: 42%                  │
├─────────────────────────────────────┤
│  ┌─────────────────────────────┐    │
│  │  ⬇  Download CSV            │    │  ← sage button
│  └─────────────────────────────┘    │
│                                     │
│  The file includes all recorded     │
│  readings. Open it in Excel or      │
│  Google Sheets.                     │
└─────────────────────────────────────┘
```

**Content:**
- Record count (current `records` from `buildDataStatusSectionHtml`).
- Date range (first and last CSV row timestamps).
- CSV size + storage usage percentage.
- Download button → existing `/download-csv` streaming handler (unchanged).

---

## 5. Sensor List Display Design

The station detail page shows every sensor in the standard node profile, using `✓` (present) or `—` (absent). The sensor set is derived from `protocol.h` `SNAP_PRESENT_*` bitmask and `SENSOR_ID_*` constants.

### Sensor display table

| Display name | Sensor ID | Bitmask bit | Unit | Group |
|---|---|---|---|---|
| Air temperature | 1001 | `SNAP_PRESENT_AIR_TEMP` (0) | °C | — |
| Air humidity | 1002 | `SNAP_PRESENT_AIR_RH` (1) | % | — |
| Spectral (8 channels) | 1101–1108 | `SNAP_PRESENT_SPECTRAL` (2) | counts | expandable |
| Wind speed | 1201 | `SNAP_PRESENT_WIND` (3) | m/s | — |
| Wind direction | 1202 | `SNAP_PRESENT_WIND` (3) | ° | — |
| Soil moisture 1 | 2001 | `SNAP_PRESENT_SOIL1` (4) | m³/m³ | — |
| Soil temperature 1 | 2003 | `SNAP_PRESENT_SOIL1` (4) | °C | — |
| Soil moisture 2 | 2002 | `SNAP_PRESENT_SOIL2` (5) | m³/m³ | — |
| Soil temperature 2 | 2004 | `SNAP_PRESENT_SOIL2` (5) | °C | — |
| Aux 1 | 3001 | `SNAP_PRESENT_AUX1` (6) | — | — |
| Aux 2 | 3002 | `SNAP_PRESENT_AUX2` (7) | — | — |
| Battery | 4001 | `SNAP_PRESENT_BAT_V` (8) | V | — |

**Display rules:**
- Wind speed and direction share a single bitmask bit; show both as `✓` or both as `—`.
- Soil 1 (moisture + temp) share a bit; show both together.
- Soil 2 (moisture + temp) share a bit; show both together.
- Spectral is one row "Spectral (8 channels)" with an expandable detail block listing all 8 wavelengths.
- Absent sensors show `—` and "(not fitted)" — never "missing" or "error".
- Values come from the last snapshot received from that station.

> **Open question:** `NodeInfo` in `node_registry.h` does not currently store `sensorPresent` or the last snapshot values. The sensor list requires either (a) adding `uint16_t sensorPresent` + a small last-snapshot cache to `NodeInfo`, or (b) looking up the last CSV row for that station from flash at page-render time. Option (a) is preferred for render speed. See §12.

---

## 6. Status Indicators and Chips

All chips use the existing `COMMON_CSS` classes, renamed in user-facing text only.

### Station status chips

| State (internal) | User label | CSS class | Colour |
|---|---|---|---|
| `DEPLOYED` | Active | `chip--state-deployed` | sage (`#7a9b70`) |
| `PAIRED` | Connected | `chip--state-paired` | terracotta (`#c47a5a`) |
| `UNPAIRED` | New | `chip--state-unpaired` | muted red (`#c45a4a`) |

### Battery chips

| Voltage range | Label | CSS class | Colour |
|---|---|---|---|
| ≥ 3.9V | OK | `chip--bat-ok` | sage |
| 3.5–3.9V | Medium | `chip--bat-med` | terracotta |
| < 3.5V | Low | `chip--bat-low` | red |

### Cloud upload status dot

| Condition | Dot colour | Label |
|---|---|---|
| `tx.enabled` + API key set + last upload < 2h | sage | Connected |
| `tx.enabled` + API key set + last upload failed | terracotta | Last upload failed |
| `tx.enabled` + no API key | terracotta | Not set up |
| `!tx.enabled` | muted grey | Upload off |

### KPI tiles (Hub Overview)

| Tile | Source | Active colour |
|---|---|---|
| Active | `deployedCount` | sage (`stat--deployed-active`) |
| Connected | `pairedCount` | terracotta (`stat--paired-active`) |
| New | `unpairedCount` | muted red (`stat--unpaired-active`) |

---

## 7. User Flows

### 7.1 First-time setup flow

```mermaid
flowchart TD
    A[Open the box] --> B[Power the Hub\nbattery or USB]
    B --> C[On your phone,\njoin WiFi: fieldmesh-xxxx]
    C --> D[Open 192.168.4.1\nportal opens automatically]
    D --> E[Hub Overview loads\n0 stations, Not set up]
    E --> F[Tap Settings]
    F --> G[Set recording interval\n5 or 10 min]
    G --> H[Tap Connect to FieldMesh\nopens /provision]
    H --> H2[Step 1: copy the FieldHub MAC,\nregister the hub in the dashboard]
    H2 --> H3[Step 2: scan or paste\nthe connection code]
    H3 --> I[Step 3: Connection saved\nuploads at the next sync]
    I --> J[Tap Add New Station\non Stations page]
    J --> K[Press pair button\non station, hold 3s]
    K --> L[Tap Find New Stations]
    L --> M[Station appears as New]
    M --> N[Tap station, tap Activate\ngive it a name]
    N --> O{More stations?}
    O -->|yes| K
    O -->|no| P[Tap Start Monitoring]
    P --> Q[Hub powers down,\nstations begin recording]
```

### 7.2 Daily check-in flow

```mermaid
flowchart TD
    A[Connect to Hub WiFi] --> B[Open 192.168.4.1]
    B --> C[Hub Overview loads]
    C --> D{All stations\nActive and green?}
    D -->|yes| E[Check cloud upload\nlast upload recent?]
    D -->|no| F[Tap station with\nred/terracotta chip]
    F --> G[Check battery +\nsensor list]
    G --> H{Fixable?}
    H -->|yes| I[Fix in field\nswap battery, reseat sensor]
    H -->|no| J[Remove station,\nre-add later]
    E --> K{Adjustments\nneeded?}
    K -->|no| L[Tap Start Monitoring\nand close]
    K -->|yes| M[Tap Settings, adjust\ninterval or upload]
    M --> L
```

### 7.3 Add station flow

```mermaid
flowchart TD
    A[On Stations page,\ntap Add New Station] --> B[Instructions panel opens]
    B --> C[Press pair button\non station, hold 3s]
    C --> D[Wait for green light\non station]
    D --> E[Tap Find New Stations]
    E --> F[Hub scans for 3 seconds]
    F --> G{Station found?}
    G -->|yes| H[Station appears in list\nas New, muted red chip]
    G -->|no| I[Try again — check\nstation is powered]
    I --> C
    H --> J[Tap the new station]
    J --> K[Tap Activate]
    K --> L[Enter name\ne.g. North Hedge 01]
    L --> M[Add notes if needed]
    M --> N[Tap Save]
    N --> O[Station now shows\nActive, sage chip]
```

### 7.4 Troubleshooting flow

```mermaid
flowchart TD
    A[Station not reporting\nno recent reading] --> B[Open Station detail]
    B --> C{Battery chip colour?}
    C -->|red Low| D[Swap battery in field]
    C -->|sage/terracotta| E{Sensor list correct?}
    E -->|sensors missing| F[Reseat sensor cables\nat station]
    E -->|sensors present| G{Last seen recent?}
    G -->|stale > 1h| H[Station may be asleep\nwait one recording interval]
    G -->|very stale| I[Remove station\nand re-add]
    D --> J[Tap Start Monitoring\nwait for next collection]
    F --> J
    H --> J
    I --> K[Re-pair station\nvia Add New Station flow]
    K --> J
```

---

## 8. What's Hidden from Users

Everything in this section is **excluded from the default view**. Items marked "Advanced only" appear in the collapsed About/Advanced `<details>` on the Hub Overview page. Items marked "Never" do not appear anywhere in the Field UI.

| Hidden concept | Visibility | Reason |
|---|---|---|
| ESP-NOW (radio protocol) | Never | Not a user concept |
| MAC addresses | Advanced only **in daily-use views**; prominent in the Connect flow (`/provision`, Settings → FieldHub identity) | Useful for support, not for day-to-day field use — but the FieldHub MAC *is* the registration identifier, so it must be easy to find while connecting. Scoped to match §3. |
| Flash / LittleFS / NVS | Never — say "Storage" | Filesystem is mechanism |
| CCHSEND / modem AT commands | Never | Modem internals |
| Phase alignment / sync anchors | Never | Scheduling internals |
| Config version numbers | Never | Sync internals |
| Firmware build strings | Advanced only | Support use only |
| Cursor offsets / retry counts | Never — show "last upload: success/failed" | Upload internals |
| `nodeId` raw hex (e.g. `ENV_94E38C`) | Shown only if no user name set | Fallback identifier |
| Sync mode (interval vs daily) | Never — presets handle it | Exposed via upload interval presets |
| `kSyncFillK` / queue fill ratio | Never | Internal tuning |
| Auth token / site ID / deployment ID | Advanced only (legacy fields) | Superseded by API key |

### About / Advanced panel (collapsed on Hub Overview)

```
┌─────────────────────────────────────┐
│  ▾ About / Advanced                 │
├─────────────────────────────────────┤
│  FieldHub MAC:  24:6F:28:6C:0A:A0   │
│                 [ Copy ]            │
│  FieldHub name: FieldMesh-6C0AA0    │
│  Radio node ID (internal): 001      │
│  Firmware:      2.1.0               │
│  Build:         2026-06-26T10:00Z   │
│  WiFi network:  fieldmesh-xxxx      │
│  Portal URL:    http://192.168.4.1  │
│  Node-radio address (support        │
│    information): 24:6F:28:6C:0A:A0  │
│  Radio channel: 11                  │
└─────────────────────────────────────┘
```

Consistent with the amended §3 MAC row: this panel is the *daily-use* placement
(collapsed), while `/provision` step 1 and Settings → FieldHub identity show the
same MAC prominently because that is where it is actually needed.

Two naming points, both fixed because they misled operators:

- **"FieldHub name"** is `hwCode()` (`FieldMesh-<last 6 of MAC>`). It is a
  hardware label, **not** the registration identifier. The Settings page used to
  present it as the value to register; it strips to 10 hex characters, and
  `normaliseFieldHubMac()` requires 12, so the dashboard rejected it.
- **"Node-radio address"** is `getMothershipsMAC()`, which returns the same STA
  MAC as the FieldHub MAC above. It is labelled as support information so the
  duplicate value cannot read as a second, different thing to register.

---

## 9. Visual Design Reference

The palette and spacing are already applied in `COMMON_CSS` (lines 473–680 of `config_server.cpp`). This section confirms the values for the redesign.

### Colour palette

| Token | Hex | Usage |
|---|---|---|
| `--bg` | `#faf8f4` | Page background (warm stone) |
| `--panel` | `#ffffff` | Cards and sections |
| `--text` | `#4a4640` | Body text |
| `--sub` | `#6b665e` | Secondary text |
| `--border` | `#e8e4dc` | Borders (warm stone) |
| `--primary` / `--btn-solid` | `#5b7553` | Primary buttons, sage |
| `--success` | `#7a9b70` | Active status, sage |
| `--warn` | `#c47a5a` | Connected status, terracotta |
| `--danger` | `#c45a4a` | New/removed/low, muted red |
| `--input-bg` | `#f5f3ee` | Form inputs |

### Typography

- Font stack: `-apple-system, BlinkMacSystemFont, "Segoe UI", Roboto, system-ui, sans-serif` (already set).
- Base size: 16px / 1.5 line-height.
- Headings: `.h1` 22px bold; section `h3` 18px.
- Labels: `.label` 0.95rem, `--sub` colour.
- Help text: `.help` 0.85rem, `--sub` colour.

### Spacing

| Token | Value |
|---|---|
| `--sp-1` | 8px |
| `--sp-2` | 12px |
| `--sp-3` | 16px |
| `--sp-4` | 20px |
| `--radius` | 10px |
| `--shadow` | `0 2px 10px rgba(74,74,72,.12)` |

### Touch targets

- All buttons: `min-height: 52px` (`.btn--action`).
- Small buttons: `min-height: 44px` on mobile (existing `@media(max-width:480px)` rule).
- Preset choice buttons: `min-height: 46px` (`.action-choice span`).

### Layout

- `.container` max-width 600px (720px on ≥768px).
- Mobile-first; the portal is only used on phones.
- Sticky header on mobile (existing rule).
- Card-based: every section is a `.section` panel with `--shadow`.

---

## 10. Implementation Notes for the Coder

### 10.1 What stays the same

- **Captive portal redirect:** all `/generate_204`, `/hotspot-detect.html`, etc. routes and `sendCaptivePortalLanding` stay unchanged.
- **Async-form pattern:** `COMMON_JS` and the `async-form` class behaviour stay. Form submissions still POST to handler routes and return `sendAjaxResult`.
- **CSS delivery:** `COMMON_CSS` stays inline in `PROGMEM`, injected by `headCommon`.
- **HTML generation:** C++ string concatenation in `config_server.cpp`. No templating engine.
- **CSV download:** `handleDownloadCSV` and `/download-csv` streaming stay unchanged.
- **Status JSON:** `buildStatusJson()` and `/ui-status` endpoint stay (used by any future JS refresh).
- **NVS persistence:** `savePairedNodes`, `loadTransmissionSettings`, `saveWakeIntervalToNVS`, etc. stay.

### 10.2 What changes

| Current | New | Notes |
|---|---|---|
| `handleRoot` | `handleHubOverview` | Rewrite content; keep route `/` |
| `handleNodesPage` | `handleStationsPage` | New route `/stations`; rename all labels |
| `handleNodeConfigForm` | `handleStationDetail` | New route `/station?id=...`; add sensor list |
| `handleUploadSettings` | `handleSettings` | New route `/settings`; fold in recording interval presets |
| `handleDownloadCSV` page link | `handleDataExport` | New route `/export` wrapper page; keep `/download-csv` stream |
| `handleShutdown` | `handleStartMonitoring` | Rename button to "Start Monitoring"; same POST behaviour |
| `handleDiscoverNodes` | `handleFindStations` | Rename; same ESP-NOW discovery burst |
| `handleSetWakeInterval` | `handleSetRecordingInterval` | Rename; accept preset button values |
| `handleSetTransmission` | `handleSaveSettings` | Rename; same field handling |

### 10.3 String changes in `COMMON_CSS`

The CSS class names can stay (they are not user-visible). Only the **text content** inside HTML strings changes. Specifically:

- "Mothership time" → "Hub time"
- "Deployed / Paired / Unpaired" KPI labels → "Active / Connected / New"
- "Discover Nodes" → "Find New Stations"
- "Node manager" → "Stations"
- "Sync & Power Down" → "Start Monitoring"
- "Node wake" → "Recording" / "Auto sync" → "Upload"
- "Flash free / Flash usage" → "Storage free / Storage used"
- "LTE upload" → "Cloud upload"
- "Pending rows" → "Readings waiting"
- "Rows uploaded" → "Readings sent"

### 10.4 New CSS additions (proposed)

- `.preset-row` — grid of preset buttons for recording/upload interval (reuse `.action-choice` pattern).
- `.sensor-list` — two-column list with `✓` / `—` indicators.
- `.sensor-present` / `.sensor-absent` — colour the indicator (sage / muted grey).
- `.status-dot` — small coloured circle for cloud upload status.
- `.about-panel` — collapsed `<details>` styling for Advanced.

### 10.5 Sensor list data source

The station detail page needs `sensorPresent` (bitmask) and last snapshot values per station. Two options:

- **Option A (preferred):** Add `uint16_t lastSensorPresent` and a small `lastSnapshot` cache (or individual float fields) to `NodeInfo` in `node_registry.h`. Populate on snapshot receive in `espnow_config.cpp`. Persist to NVS.
- **Option B:** Read the last CSV row for the station from `/datalog.csv` at render time. Slower, but no struct change.

> **Open question — see §12.** Coder should confirm which option before implementing.

### 10.6 Hub battery

The Hub Overview wants a Hub battery chip. Currently `buildStatusJson()` does not include Hub battery voltage. The mothership firmware would need to read its own battery voltage (ADC) and expose it. This is a firmware change outside the config server — flagged as an open question.

### 10.7 Mobile browser compatibility

- Test on Safari (iOS) and Chrome (Android).
- No JavaScript frameworks; only the existing `COMMON_JS` inline script.
- `<meta name="viewport" content="width=device-width, initial-scale=1">` already set in `headCommon`.
- `-webkit-tap-highlight-color: transparent` already set.
- All buttons meet 44px minimum touch target.

---

## 11. Migration Plan

### 11.1 What changes

| Area | Change |
|---|---|
| Routes | `/nodes` → `/stations`, `/node-config` → `/station`, `/upload` → `/settings`, add `/export` |
| Handler function names | Rename to match new terminology (see §10.2) |
| All user-visible strings | Apply terminology mapping (§3) |
| Hub Overview | Rewrite `handleRoot` content; add cloud status, storage, schedule summary |
| Stations page | Rewrite `handleNodesPage` cards; add sensor count, last reading summary |
| Station detail | Rewrite `handleNodeConfigForm`; add sensor list (needs data — see §10.5) |
| Settings page | Merge `handleUploadSettings` + recording interval into one page; preset buttons |
| Data Export | New wrapper page around existing CSV download |
| About/Advanced | New collapsed panel on Hub Overview |

### 11.2 What stays

| Area | Why it stays |
|---|---|
| Captive portal routes | Required for phone auto-open |
| `COMMON_CSS` palette | Already matches dashboard |
| Async-form pattern | Works, no reason to change |
| `buildStatusJson()` | Used by JS refresh |
| NVS persistence layer | Stable |
| CSV streaming handler | Stable |
| ESP-NOW discovery burst | Stable, just renamed in UI |
| `headCommon` / `footCommon` structure | Stable |

### 11.3 Sequencing (for Coder)

1. **Terminology pass** — rename user-visible strings only, no layout change. Validates wording.
2. **Hub Overview rewrite** — new `handleRoot` content.
3. **Stations + Station detail** — new cards, sensor list (requires §10.5 decision).
4. **Settings merge** — fold upload settings + recording interval into one page.
5. **Data Export page** — wrapper around existing CSV download.
6. **About/Advanced panel** — collapsed details on Hub Overview.
7. **Route aliases** — add redirect from old routes (`/nodes` → `/stations`, etc.) for any bookmarked URLs.

> **Open question:** whether old routes should redirect or just 404. Proposed: redirect during migration, remove after one release.

---

## 12. Open Questions

1. **Sensor list data source.** `NodeInfo` has no `sensorPresent` bitmask or last-snapshot values. Does Coder add fields to `NodeInfo` (Option A, preferred) or read from CSV at render time (Option B)? *Decision needed before §10.5 implementation.*

2. **Hub battery voltage.** `buildStatusJson()` does not currently expose Hub battery. Is there an ADC read available on the mothership for its own battery, or is the Hub battery chip omitted from the first redesign pass?

3. **"Next collection time" on Hub Overview.** Should this be the next fleet sync window (`computeNextSyncIsoLocal`) or the next earliest station wake? Proposed: fleet sync window, labelled "Next collection".

4. **Last reading headline value.** The station card shows one value (e.g. "22.1°C"). Which sensor is the headline — air temp (if present), else battery, else first available? Proposed: air temp if present, else battery voltage, else "—".

5. **Route backwards compatibility.** Should `/nodes`, `/node-config`, `/upload` redirect to their new equivalents, or return 404? Proposed: redirect for one release, then remove.

6. **Upload interval presets.** The "18 min" preset assumes the current auto-sync fill ratio (`kSyncFillK`). Should "18 min" be a fixed preset or derived from the recording interval? Proposed: fixed preset list as specified in §4 Page 3.

7. **Manual upload button.** The current "Upload now" button is in Advanced settings. Should it remain there, or appear on the Hub Overview cloud status card? Proposed: keep in Advanced only — manual upload draws extra power and is not a daily action.

8. **Station "last reading" timestamp.** `NodeInfo` has `lastSeen` (ms) and `lastNodeTimestamp` (unix). Which should be displayed as "Last reading"? Proposed: `lastNodeTimestamp` if available, else `lastSeen`.

9. **Spectral detail expansion.** Should the 8 spectral channels always be shown expanded on the station detail, or collapsed behind a tap? Proposed: collapsed by default, tap to expand — keeps the sensor list scannable.

10. **About/Advanced MAC display.** Is the Hub MAC address useful enough to field users to justify showing it in Advanced, or should it be removed entirely? Proposed: keep — support staff may ask for it.

---

*End of document. This is a design document — no code changes. Hand off to Coder for implementation after open questions in §12 are resolved.*

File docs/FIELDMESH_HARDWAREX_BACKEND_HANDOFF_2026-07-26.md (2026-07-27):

# Handoff prompt — backend/frontend verification for the HardwareX manuscript

**Paste this ahead of `FIELDMESH_HARDWAREX_MANUSCRIPT_2026-07-26.md` when opening the backend/frontend repo.**

---

## Context

The attached document is a draft manuscript for *HardwareX* (Elsevier) describing the FieldMesh microclimate
monitoring platform. It was written and fact-checked against the **firmware** repository
(`Data-Logger-network---ESP32`), where every device-side claim has been verified against source.

The manuscript contains claims about the **cloud dashboard and backend** that could not be verified there, because
that code lives in this repository. Those claims are marked `[UNVERIFIED]` — see **§6.6 Cloud dashboard and remote
management**, and the pointers in §2.4 (soil calibration), §6.5 (upload), and §7.6 (timebase).

**This document is not a specification and not a change request.** Nothing here should be implemented, refactored, or
"made to match". The task is the opposite: tell me what this repository *actually does today*, so the manuscript can
be corrected to match reality, or the claim removed. A published paper that overstates what the system does is worse
than a paper that claims less.

## What I need back

For each item below: **confirmed / partly true / not true / not implemented**, with a file-and-line pointer where it
exists. Where a claim is wrong, give me the accurate one-sentence version I can drop into the manuscript.

**A. §6.6 dashboard claims**

1. Projects are containers for one field deployment, private to the owner's account, enforced by Postgres row-level security.
2. A FieldHub is registered by entering or scanning its MAC; the dashboard confirms the match by displaying a hardware code of the form `FieldMesh-<last 6 of MAC>`.
3. A per-hub connection key is generated with a QR code, stored **hashed**, and can be re-minted and re-provisioned if lost or leaked.
4. The dashboard never contacts a device directly — it records durable intent that the hub pulls on its next scheduled check-in.
5. Remote commands run **Queued → Accepted → Applied**, and can be cancelled while still Queued.
6. A sleeping node is not counted as changed until it acknowledges.
7. A paused node displays as *Paused* (not a fault), and shows *Resuming* for one interval after resume.
8. A project-wide recording-interval change is a single coordinated transition that preserves the sync anchor so no readings are lost.
9. Undeploy is local-only by design and is not exposed remotely.
10. Hub self-update over LTE is exposed/managed from the dashboard.

**B. Data-path claims made in the firmware-side text**

11. **Soil moisture** — the node logs raw sensor volts and the **backend** performs the volts → volumetric water content conversion, so calibration curves can be updated without reflashing nodes. Is that conversion implemented? If yes, what curve, and is it per-probe or global? If no, say so — the manuscript currently presents deferred calibration as a design feature.
12. **Spectral metadata** — Clear, NIR, gain, integration time, and the saturation flag arrive and persist as finite values (there was a null-metadata defect fixed 2026-07-04 on the firmware side).
13. **Ingest shape** — the hub posts a flat JSON array of readings plus `{meta, status}`, keyed by mothership UUID and device MAC, with 400/401 treated as non-retryable. Confirm the endpoint contract still matches.
14. **Timebase** — this one matters most. The manuscript states that the hub's DS3231, set from the operator's browser in **UTC**, is the sole clock authority, and that **backend-supplied time never overrides the hub RTC**. A backend `serverTimeUnix` field previously carried *local* time and desynchronised the fleet by two hours. Confirm the backend no longer asserts an authoritative time, and that any human-facing local-time display happens purely in the presentation layer.

**C. Scope question for me to decide**

15. How much of the cloud path can be honestly evidenced today? The firmware side is bench-validated at the transport level (AT handshake, SIM, registration, chunked HTTPS, and a full 1.3 MB cloud-OTA image download), but there is **no completed field-upload campaign** in the firmware repo. If the backend has ingest logs from real deployed hardware, tell me the date range and volume — that would let §6.5 and §7.5 say more. If not, §6.6 will likely be cut from the paper and the on-site CSV log presented as the primary data product.

## Hard constraints

- **Do not open-source or publish this repository.** The backend and dashboard are deliberately staying closed. The published artefacts are the PCB designs, the printed sensor housings, and the device firmware only. Do not add licence files, deposit anything, or reference this repo's contents in the manuscript beyond what I ask for above.
- **Do not change any device-facing contract** to make a manuscript claim true. The firmware is the fixed side here; if the two disagree, I fix the manuscript.
- **Do not treat the manuscript's wording as the intended design.** Some of it is my compression of firmware behaviour and may be subtly wrong about the backend.

## Output format

A short markdown report — numbered to match the list above — with:

- a verdict per item,
- a file/line pointer where the behaviour lives,
- a corrected one-sentence claim wherever mine is wrong,
- and a flat list at the end of any claim I should simply delete.

No code changes, no PRs.

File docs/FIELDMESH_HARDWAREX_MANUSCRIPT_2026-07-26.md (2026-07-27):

# An open-source ESP32 microclimate monitoring platform for fine-scale ecological applications

> **Draft status — 2026-07-26.** Working draft, updated as features land. Verified line-by-line against the firmware
> repository (`Data-Logger-network---ESP32` @ `e8acf05`) and, for the cloud path, against the dashboard repository
> (`FieldMeshDashboard` @ `0102661`) and its live Supabase project.
>
> Scope decisions applied: the ultrasonic wind pathway is out; node and hub electronics go in commercial IP-rated
> junction boxes; the firmware is published whole with an optional local-only build configuration.
>
> **Evidence conventions.** `*PLACEHOLDER*` marks content still to be written or measured. `[EVIDENCE GAP]` marks a
> claim that is implemented and correct but not yet backed by data strong enough to publish — each one states what
> would close it, so the claim can be kept in view and upgraded rather than quietly dropped. Nothing marked
> `[EVIDENCE GAP]` should reach submission in that state: it is either evidenced or removed.
>
> The working appendices at the end (Open items, Change log) are for internal review and should be stripped before
> submission.

> **Title options:**
> - *(current — broader, 12 words)* An open-source ESP32 microclimate monitoring platform for fine-scale ecological applications
> - *(PV-specific)* An open-source ESP32 microclimate monitoring platform for solar photovoltaic landscapes
> - *(with project name)* FieldMesh: an open-source microclimate monitoring network for heterogeneous landscapes
>
> The broader framing widens the HardwareX audience. The solar PV application is prominent in §1 and the abstract, and links directly to Armstrong et al. (2026).

## Authors

Tom Armstrong, Bradley Evans, Eric J. Nordberg*

## Affiliations

Ecosystem Management, School of Environmental and Rural Science, University of New England, Armidale, NSW 2351, Australia

## Corresponding author

*Eric J. Nordberg — Eric.Nordberg@une.edu.au
ORCID: 0000-0002-1333-622X

---

## Abstract

Fine-scale microclimatic variation shapes organism physiology, behaviour, and survival, yet conventional meteorological stations and commercial loggers cannot resolve metre-scale heterogeneity across local microhabitats. This gap limits spatially replicated ecological research, particularly in solar photovoltaic (PV) facilities, where panels, inter-row corridors, and edge zones create distinct microclimatic mosaics (Armstrong et al., 2026). Here we present an open-source, low-cost microclimate monitoring platform built on custom ESP32-based sensor nodes. Each node measures air temperature, relative humidity, spectral light, soil moisture, soil temperature, and wind speed, with the thermal and radiometric sensors mounted in script-generated housings that fix their exposure geometry across builds. Nodes communicate via ESP-NOW to a central field hub providing node discovery, over-the-air configuration, time synchronisation, local logging, and a browser-based field interface — without internet or cellular infrastructure, with an optional LTE backhaul where coverage permits. Both nodes and hub power-gate fully between scheduled wakes, persisting all runtime state in non-volatile memory, which eliminates between-wake current draw and enables automatic recovery after power loss. Bench commissioning confirmed integrated multi-node operation across repeated wake–synchronise cycles, with ESP-NOW delivery of ~99.7 % at 30 m line-of-sight and 84–87 % at 100 m under obstructed line-of-sight. The platform provides a reproducible, transparent framework for distributed microclimate monitoring in renewable energy and other heterogeneous landscapes.

## Keywords

microclimate monitoring; open-source hardware; ESP32; solar photovoltaic; wireless sensor network; environmental sensors

---

## Specifications table

| Field | Value |
|---|---|
| Hardware name | FieldMesh Monitoring system |
| Subject area | Environmental, planetary and agricultural sciences |
| Hardware type | Field measurements and sensors |
| Closest commercial analog | HOBO MX2301A (Onset, ~$150–250 USD per unit, temperature and humidity only); Campbell Scientific CR1000X datalogger systems (~$1,000+ USD per unit); Thermochron iButton DS1921/DS1922 (~$30–80 USD per unit, temperature only). No single commercial system integrates air temperature, relative humidity, spectral light, soil moisture, soil temperature, and wind sensing in a low-cost, open-source, wirelessly networked package designed for fine-scale ecological replication. |
| Open source license | PCB designs: CERN-OHL-S-2.0. Firmware: MPL-2.0. Printed sensor housings: CC BY 4.0. *PLACEHOLDER — proposed, pending confirmation and a UNE IP-ownership check (see Open items).* The SHT4x radiation shield is a derivative work whose CC BY 4.0 terms are inherited and settled. |
| Cost of hardware | *PLACEHOLDER — see §4 for the derivation and what the BOM price columns do and do not cover.* |
| Source file repository | *PLACEHOLDER: Upload design files to OSF or Zenodo and insert DOI URL here* |

---

## 1. Hardware in context

Microclimate — the conditions organisms experience at centimetre-to-metre scales — shapes physiology, behaviour, and survival (Pincebourde et al., 2016). Because organisms respond to their immediate thermal, radiative, and moisture surroundings rather than regional averages, fine-scale variation can exert stronger ecological influence than coarse-scale weather data (Kemppinen et al., 2024). Standard meteorological stations are designed to minimise local variability and therefore often fail to capture heterogeneity within soil layers, vegetation canopies, cavities, or near-surface boundary layers (De Frenne et al., 2025; Maclean et al., 2021). These mosaics change over metres or even centimetres, and biologically meaningful extremes — rapid heating, transient wind shifts, short-term thermal fluctuations — can unfold over minutes to hours (Chen et al., 2024; Maclean et al., 2021). Capturing this spatiotemporal heterogeneity is increasingly recognised as essential for predicting ecological responses to climate change, identifying microrefugia, and informing habitat restoration (De Frenne et al., 2025).

Solar photovoltaic (PV) farms are a rapidly expanding land use that generates just such microclimatic mosaics (Liu et al., 2026). Elevated panels, inter-row spacing, and supporting infrastructure create distinct microhabitat zones — under-panel, inter-row, and edge — that differ in radiation, wind exposure, temperature, and moisture (Armstrong et al., 2026). Under-panel areas typically experience reduced shortwave radiation and moderated soil temperatures (Li et al., 2025; Wu et al., 2022), while inter-row zones remain more directly exposed to open-air conditions. These gradients have direct implications for the co-use potential of solar farms, influencing wildlife habitat suitability, vegetation growth, and livestock welfare (Armstrong et al., 2026; Nordberg et al., 2021; Nordberg & Schwarzkopf, 2023). As PV installations expand into multi-use agrivoltaic and conservoltaic landscapes, resolving these fine-scale gradients will be essential for evaluating ecological and agricultural outcomes — yet they occur at metre and sub-metre scales largely undetected by conventional monitoring.

Despite growing recognition that fine-scale microclimatic variation influences wildlife habitat suitability and conservation planning (Crowley et al., 2026; Enochs et al., 2025; Saikumari et al., 2025), a practical monitoring gap persists. High-end atmospheric systems — eddy covariance towers, WMO-style stations (Baldocchi, 2003; World Meteorological Organization, 2018), and global networks such as FLUXNET, OzFlux, and NEON (Baldocchi, 2003; Beringer et al., 2022; Metzger et al., 2019) — provide valuable ecosystem-scale data but are not designed to resolve centimetre- to metre-scale heterogeneity across local microhabitats.

For fine-scale ecological monitoring, existing logger systems present practical constraints. Sensor combinations are often predefined within hardware configurations, limiting flexibility as research questions evolve (Hayibo & Pearce, 2025). Remote deployments may require periodic physical access for configuration, data retrieval, or maintenance, which becomes increasingly impractical as network size grows (Ďud'ák et al., 2023). Long-term autonomous monitoring also requires trade-offs between power consumption, storage efficiency, firmware design, and sampling density (Ďud'ák et al., 2023). Where fine-scale heterogeneity requires dense spatial replication, per-unit hardware cost directly constrains achievable sampling resolution.

Although open-source platforms have demonstrated that modular systems can reduce cost and improve flexibility (Ali et al., 2016; Hayibo & Pearce, 2025), fewer studies provide detailed, reproducible descriptions that integrate enclosure geometry, field durability, firmware architecture, and ecological deployment strategy into a cohesive monitoring framework. For microclimate monitoring, the physical design of a logger is not separate from the measurements it produces: sensor height, exposure, shielding, airflow, and housing geometry can all influence recorded temperature, humidity, radiation, and wind conditions (Maclean et al., 2021). Systems designed for heterogeneous PV landscapes therefore need to support consistent sensor placement, low-cost replication, and flexible deployment across under-panel, inter-row, edge, and open reference microsites (Armstrong et al., 2026).

Here, we present the design and bench commissioning of an open-source, reproducible, and modular microclimate monitoring platform for fine-scale ecological applications. The platform integrates air temperature, relative humidity, spectral light, soil moisture, soil temperature, and wind speed within a custom ESP32-based node architecture, together with a parametric, script-generated set of sensor housings that fix the exposure and shielding geometry of the radiometric and thermal sensors. By documenting both the system design and its current bench-commissioned limits, this work provides a foundation for future validation and spatially replicated monitoring of the environments that organisms experience in renewable energy landscapes.

---

## 2. Hardware description

The platform was developed as a custom hardware and firmware system guided by five design principles: (1) reproducibility and low-cost replication; (2) distributed sensing with centralised aggregation; (3) modular sensor integration; (4) measurement-aware mechanical design; and (5) environmental robustness with field configurability.

### 2.1 System architecture

The system comprises battery-powered sensor nodes and a central field hub, both built on custom PCBs carrying an ESP32-WROOM-32D-N4 module, designed in EasyEDA and fabricated through JLCPCB. The sensor node described here is the NODE_v3 hardware revision, a hardened iteration of the prior NODE_v2 board with refined power and charging circuitry; electrical bring-up confirmed parity with NODE_v2 across every subsystem used by the platform described here. Nodes measure environmental variables and transmit wirelessly via ESP-NOW (channel 11) to the hub, which coordinates node management, time synchronisation, local data logging, and a browser-based field interface. An optional LTE backhaul (SIMCom A7670G Cat-1 modem) enables cloud upload where cellular coverage exists; where it does not, the modem section is left unpopulated and data are retained locally on the hub.

Each node carries a DS3231 real-time clock backed by a CR1220 coin cell, which serves as the sole time authority and wake source. The hub maintains its own DS3231 and is the clock authority for the fleet; it is set from the operator's browser in UTC, and all recorded timestamps throughout the system are UTC.

### 2.2 Power architecture: hard power-cut, not sleep

A defining feature of the design is that neither nodes nor the hub enter deep sleep between scheduled tasks — they power off entirely.

**Node.** On completing a wake cycle, the node releases a power-hold latch (`PWR_HOLD`, GPIO23) and the board loses all power. Wake is initiated by a DS3231 alarm, whose interrupt is inverted and drives a high-side P-channel MOSFET latch that switches the system rail (`VSYS`) on; the ESP32 then boots, re-asserts `PWR_HOLD`, and only then clears the alarm flag. The order matters — clearing the alarm before asserting `PWR_HOLD` would drop the rail mid-boot. An always-on keep-alive LDO powers the RTC and its CR1220 backup while the main system is off.

**Hub.** The hub uses the same principle on a different trigger set. It wakes on any of three sources, resolved in firmware to a single wake reason: a DS3231 Alarm 1 (scheduled sync and upload), a config-button press latched by an SN74LVC2G74 flip-flop (operator servicing), or USB VBUS presence (bench and service mode). A config-button wake takes priority over a concurrent RTC alarm, so an operator can always seize the device at a site visit. The hub holds `PWR_HOLD` (GPIO26) for the duration of its task and clears the config latch (GPIO25) on exit.

This architecture eliminates quiescent draw between tasks and extends battery life. Because RTC memory does not survive the power cut, all runtime state — hub association, deployment status, sampling interval, synchronisation metadata, sensor selection, and the queued snapshot buffer — is persisted in non-volatile storage (NVS) and reloaded on every boot. A hardware timer watchdog (120 s) reboots the node if a hung loop — for example an I²C stall — would otherwise leave it powered on and draining the pack.

The node uses a single-cell 3000 mAh LiPo with dual charging: a CN3163 solar charger and a TP5100 USB-C charger, allowing field recharging via a small solar panel or USB. Reverse-polarity protection is provided by a P-channel FET plus a resettable fuse.

### 2.3 Dual-alarm wake schedule

The DS3231 drives two independent alarms:

- **Alarm 1 (data wake):** fires at `now + wakeInterval`, triggering sensor capture to a local queue with the radio off.
- **Alarm 2 (sync wake):** fires at a fleet-shared, minute-aligned phase anchor, opening the ESP-NOW radio for a coordinated synchronisation session.

When both alarms fall on the same wake, the node samples first, then synchronises, in a single power cycle. The synchronisation interval is auto-derived from the wake interval (×18) and is not user-settable; §2.5 explains why the multiplier is fixed.

### 2.4 Sensor payload

Each node carries a fixed environmental payload plus expansion capacity:

| Measurement | Sensor | Interface |
|---|---|---|
| Air temperature and relative humidity | Sensirion SHT4x (SHT40/41) | I²C 0x44 via mux ch0 |
| Spectral light (8 visible bands + Clear + NIR) | ams AS7341 | I²C 0x39 via mux ch1 |
| Soil moisture and temperature (×2 probes) | CWT TH-A via ADS1015 (12-bit ADC) | I²C 0x48, analog A0–A3 |
| Wind speed | WH-SP-WS01 reed-cup anemometer | GPIO4 pulse count |
| Battery voltage | On-board divider | GPIO35 ADC |

The AS7341 reports eight visible channels with nominal centres at 415, 445, 480, 515, 555, 590, 630 and 680 nm, plus a Clear channel and a near-infrared channel. Each snapshot also carries the acquisition metadata needed to interpret those counts — gain, integration time, and a saturation flag — so a reading can be rejected or rescaled downstream rather than being silently misinterpreted.

Digital sensors are isolated through a TCA9546A four-channel I²C multiplexer (address 0x71), with channels 0–1 assigned to the standard payload and channels 2–3 reserved for expansion. The root I²C bus (SDA = GPIO18, SCL = GPIO19) carries the RTC, the multiplexer, and the soil ADC directly; a PCA9306 level translator bridges to the expansion side. Two auxiliary I²C slots (AUX1/AUX2) and two analog channels support site-specific additions. A per-node sensor mask selects which sensors are active at deployment: self-identifying I²C parts (SHT4x, AS7341) are auto-detected, while passive sensors (wind, soil, AUX) are registered only when their mask bit is set.

The reed-cup anemometer uses an adaptive two-stage acquisition to keep the wake short in calm conditions: a 2 s presence probe and, only if at least two edges are seen, a 10 s averaging window. Reed contact bounce is rejected by a 5 ms debounce in the interrupt handler, and the two-edge minimum also discards a single stray electrical glitch. Frequency is converted to wind speed with the manufacturer's linear constant (1 Hz = 2.4 km h⁻¹, i.e. 0.6667 m s⁻¹ per Hz). This sensor reports wind speed only; wind direction is reserved in the data schema but is not populated.

Soil moisture is logged as raw sensor volts. Conversion to volumetric water content is deferred rather than performed on-node, so probe-specific calibration curves can be applied during analysis without reflashing; the platform does not yet ship a calibration curve, and the published data product is uncalibrated probe voltage (§7.5). Soil temperature is converted on-node using the CWT TH-A transfer function.

### 2.5 Coordinated synchronisation and data queue

Nodes do not transmit on every wake. Readings are captured to a checksummed non-volatile queue and flushed during the scheduled sync window. The queue is a ~3.5 kB circular byte slab held in NVS, storing variable-length records (one per wake) under an FNV-1a checksum over the whole structure, with a layout identifier so a firmware upgrade cannot misread an older blob. A record is admitted only if the whole record fits; if the slab is full the oldest records are dropped and the new record is tagged with a `DROPPED` quality flag, so the loss is visible in the data rather than silent.

Queue overflow is prevented structurally rather than by runtime clamping. The sync interval is auto-derived as `syncMin = wakeMin × 18`, which places worst-case queue fill at approximately 82 % of the safe ceiling of 22 wakes for a fully populated payload, leaving roughly four wakes of headroom. Because the multiplier is fixed in firmware and the sync interval is never exposed to the operator, a correctly configured node cannot overflow its queue during normal operation — it would have to miss six consecutive sync windows before overflow became possible.

The hub opens a bounded, coordinated pull session: it rosters nodes via jittered hellos, grants each a fairness-limited transmission window, and confirms receipt before the node pops records from its queue. Records are only removed after delivery confirmation, preventing silent data loss, and a wall-clock deadline prevents a single node's flush from consuming the entire listen window. Session and grant identifiers make late packets from an earlier wake harmless. If a node misses a sync window, its queue is left intact and its alarms re-armed.

Each wake produces a single structured snapshot (`NODE_SNAPSHOT2`) rather than one packet per sensor: a 48-byte header plus up to 33 six-byte key–value readings, keeping the largest possible packet at 246 bytes, inside the 250-byte ESP-NOW limit. Every wire structure in the shared protocol header is size-locked with a compile-time assertion, so a field added on one side cannot silently desynchronise node and hub. If a node's last time sync is older than 24 hours, it runs a bounded ESP-NOW recovery during a data wake; the hub independently assists nodes it infers are stale.

### 2.6 Field hub, storage, and connectivity

The field hub (FieldHub V2) is a custom PCB hosting an ESP32-WROOM-32D-N4, a DS3231MZ RTC (I²C on SDA = GPIO21, SCL = GPIO22), USB-C charging and serial (CH340C), a config-button wake latch, and two local storage paths: an internal LittleFS partition and a microSD card socket on SPI (CS = 13, SCK = 18, MISO = 19, MOSI = 23). Where cellular coverage permits, a SIMCom A7670G Cat-1 LTE modem provides cloud upload over HTTPS; it is powered through a TPS63020 buck-boost with a soft-started rail and communicates over Serial2 (TX = GPIO17, RX = GPIO16) at 115 200 baud through level shifters, using the modem's own TLS stack with chunked 1 kB transfers.

Storage is tiered by intent. The LittleFS partition (768 kB) is the working store: it buffers received snapshots and holds the upload queue between hub wakes. The microSD socket provides bulk archival capacity for deployments without a backhaul, where the hub must retain a full season of data locally. At the time of writing the snapshot logging path writes to LittleFS only, and routing it to the card is scheduled for the next hub hardware revision (§7.5).

The hub serves a captive-portal Wi-Fi access point (SSID `FieldHub(<MAC>)`, WPA2-protected, on the same channel 11 as the ESP-NOW link, maximum four clients, reachable at 192.168.4.1) through which a phone, tablet, or laptop can discover nodes, assign identities, set sampling intervals, select sensors, deploy or stop nodes, and export data — all without reflashing or serial reconfiguration.

Over-the-air configuration is declarative and version-gated: the hub holds each node's desired state and re-broadcasts it every sync window until the node's echoed config version matches. Changeable without reflashing: wake interval, sensor mask, deploy/stop/unpair, sync phase, and RTC time.

Firmware images are updated through a separate signed pathway rather than through the configuration channel. The mechanism — an Ed25519-signed manifest, a SHA-256 gate over the image, A/B application slots, and deferred-verify rollback on the stock ESP32 bootloader — is common to both device roles and has been bench-proven on both node and hub silicon. The delivery paths differ in maturity: the hub can fetch, verify, and install a release over LTE end-to-end (bench-proven on a 1.3 MB image), whereas nodes report their firmware and slot state to the hub but have no image-transfer path, because a power-gated node is only reachable for a short window each sync cycle. Node firmware update therefore remains a documented design, not a delivered capability (§7.5).

### 2.7 Deployment without connectivity

The platform is designed to be useful with no internet or cellular infrastructure at all, and this is the configuration we expect most ecological deployments to use. The ESP-NOW link, coordinated sync, scheduling, node configuration, local logging, and the browser-based field interface are all local to the hub and require no backhaul. Where LTE is not needed, the modem, its buck-boost converter, and its level shifters are simply left unpopulated (§5.5), which removes their cost and their current draw. *PLACEHOLDER: a corresponding firmware build configuration that compiles out the modem and upload paths is planned but not yet implemented; until then an unpopulated hub simply fails its modem probe and continues to log locally.*

### 2.8 Field hub duty cycle and remote management

Because the hub power-gates like the nodes, its behaviour is scheduled rather than continuous. On an RTC-alarm wake it opens the sync window (nominally 120 s, long enough to roster and drain multiple nodes against each node's ~60 s listen window), writes received snapshots to local storage, optionally uploads over LTE, re-arms its alarm, and powers down. On a config-button wake it instead brings up the Wi-Fi access point and stays available for operator interaction until the operator finishes. The browser interface is therefore not continuously available at a deployed site: an operator presses the config button to summon it. This is a deliberate design property, not a limitation of the interface.
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

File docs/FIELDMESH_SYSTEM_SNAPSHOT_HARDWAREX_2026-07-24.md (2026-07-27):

# FieldMesh — System Technical Snapshot (HardwareX paper reference)

**Compiled:** 2026-07-24 · **Source:** `Data-Logger-network---ESP32` firmware repository (node V3 + mothership/FieldHub V1/V2)

> Scope note: this document reports what is *in the repository as of the compile date* — firmware source, hardware design notes, and bench validation records. Where a value is design-intent-only, bench-verified, or still uncertain, it is flagged. Two chip-identity questions from the brief (ADS1015 vs ADS1115, AS7341 vs AS7343) are answered explicitly in §1 and §6.

---

## 1. Node hardware (NODE_v3)
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

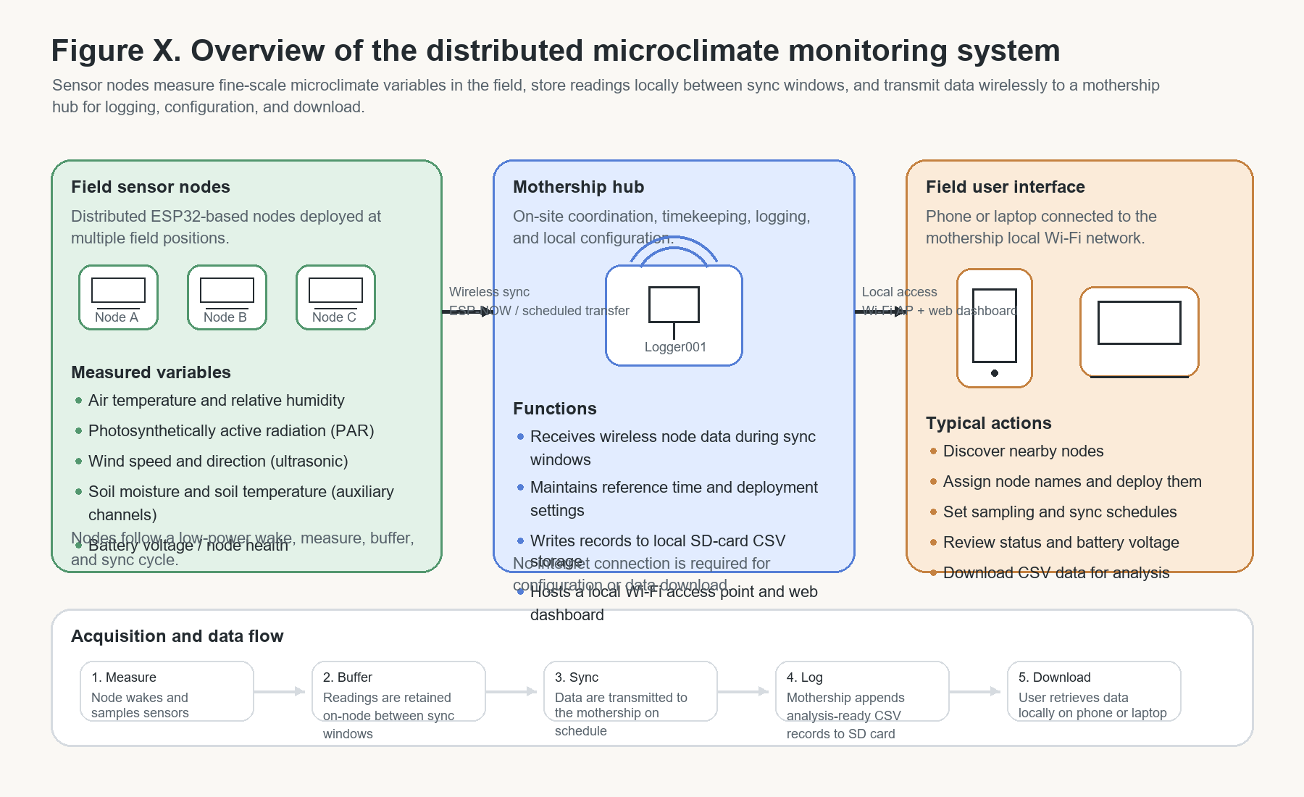
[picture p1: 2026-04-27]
docs/ERS381_overview_figure.png

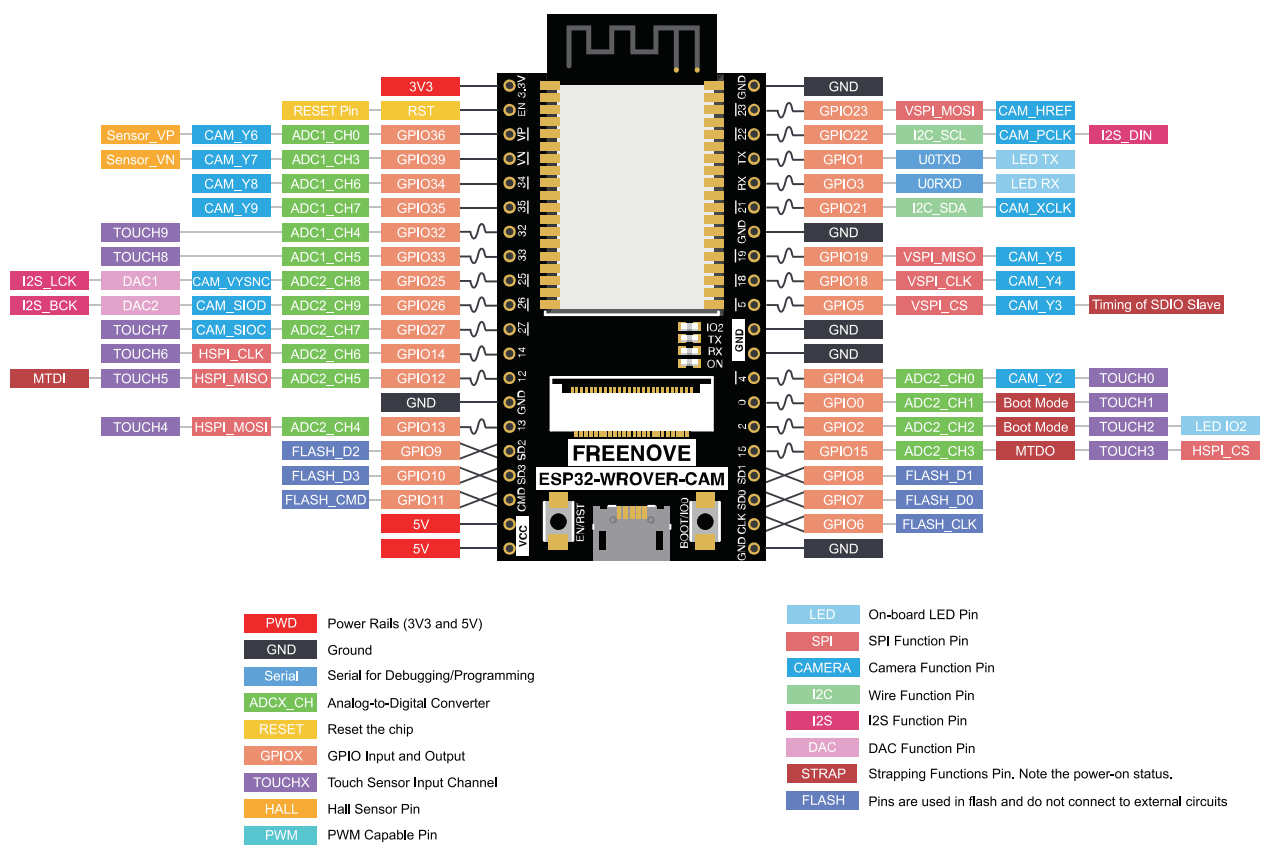
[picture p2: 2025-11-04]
docs/assets/reference/Freenove-ESP32-Wrover-CAM-pinout.png

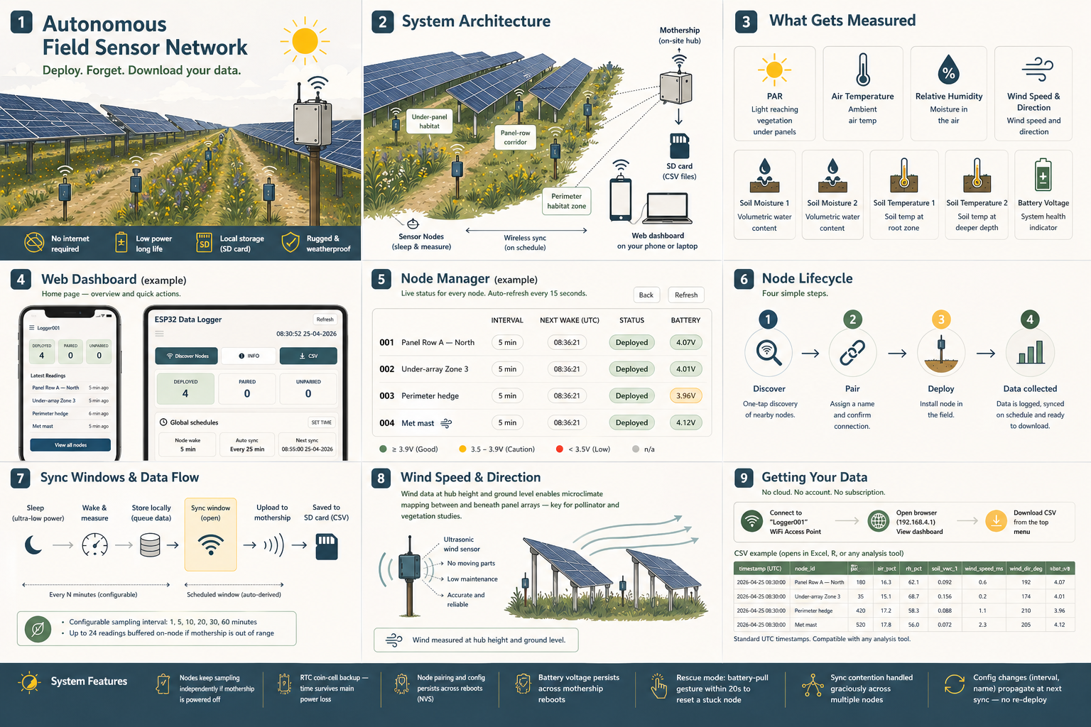
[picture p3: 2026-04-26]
docs/ChatGPT Image Apr 26, 2026, 10_26_01 AM.png

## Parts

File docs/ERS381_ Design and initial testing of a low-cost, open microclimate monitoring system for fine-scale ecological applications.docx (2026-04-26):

# *Intended Audience

This manuscript is intended for biologists and ecologists interested in monitoring abiotic variables at fine spatial scales. It is not written as a specialist electronics or embedded systems engineering paper. The technical architecture is described in sufficient detail to ensure transparency, reproducibility and practical implementation, but the narrative prioritises clarity over technical depth. Engineering concepts are explained in plain language, with acronyms and hardware terminology introduced only where necessary and defined clearly. The manuscript aims to occupy a middle ground between ecology and instrumentation: rigorous enough to be reproducible, but accessible to researchers without formal training in electronics or firmware development. The emphasis is on ecological applicability, system design logic and deployment considerations rather than low-level circuit analysis or firmware optimisation.

# Title

Design and initial testing of a low-cost, open microclimate monitoring system for fine-scale ecological applications

A modular ESP32-based logger with an ultrasonic anemometer and integrated PAR sensing

1. Introduction

Microclimate, the climatic conditions experienced by organisms at spatial scales of centimetres to metres, plays a central role in shaping physiological performance, behaviour and survival. Because organisms respond to the thermal, radiative and moisture conditions of their immediate surroundings rather than to regional atmospheric averages, fine-scale climatic variation often exerts stronger ecological influence than coarse-scale weather data (Kemppinen et al., 2024). Standard meteorological stations are intentionally designed to minimise local variability, measuring temperature, humidity and wind under well-ventilated, standardised conditions at fixed heights above ground. While essential for regional climate monitoring, such measurements frequently fail to capture the heterogeneity experienced within soil layers, vegetation canopies, cavities or near-surface boundary layers (De Frenne et al., 2025; Maclean et al., 2021).

Microclimatic conditions can vary dramatically over short horizontal and vertical distances. Vegetation structure, surface albedo, soil moisture, topography and airflow interact to generate mosaics of temperature, humidity and radiation that change over metres or even tens of centimetres. Near the ground, conductive and convective heat exchange create steep gradients that diverge substantially from free-air meteorological measurements (Maclean et al., 2021). Temporal variability is equally important. Biologically meaningful extremes such as rapid heating events, short-term thermal fluctuations or transient wind shifts can unfold over minutes to hours (Chen et al., 2024; Maclean et al., 2021). Capturing this spatiotemporal heterogeneity is increasingly recognised as essential for predicting ecological responses to climate change, identifying microrefugia and informing habitat management and restoration (De Frenne et al., 2025)

Solar photovoltaic (PV) farms represent a rapidly expanding land use that generates complex microclimatic mosaics (Liu et al., 2026). The arrangement of elevated panels, inter-row spacing and supporting infrastructure creates distinct microhabitat zones, including under-panel environments, open inter-row corridors and transitional edge areas. These zones differ in incident radiation, wind exposure, surface temperature and moisture dynamics as panels modify incoming solar radiation and alter near-surface energy and water fluxes (Li et al., 2025; Liu et al., 2026; Wu et al., 2022). Under-panel areas typically experience substantial reductions in shortwave radiation and moderated soil temperatures (Li et al., 2025; Wu et al., 2022), while inter-row zones remain more strongly coupled to atmospheric forcing. Edge zones can combine shading gradients with lateral redistribution of water and airflow, generating additional spatial heterogeneity (Liu et al., 2026; Wu et al., 2022). Such spatial structure occurs at meter and sub-meter scales and is largely invisible to conventional meteorological monitoring. As solar energy infrastructure expands globally, the spatial complexity of PV-induced microclimates underscores the need for scalable, modular monitoring systems designed specifically to resolve meter-scale environmental gradients within renewable energy landscapes.

Despite growing recognition of the importance of microclimate, a monitoring gap persists. High-end atmospheric systems, including eddy covariance towers and World Meteorological Organization (WMO) style stations, are designed to quantify ecosystem-scale fluxes and spatially integrated atmospheric conditions (Baldocchi, 2003; World Meteorological Organization, 2018). Global networks have demonstrated the power of these approaches for understanding carbon, water and energy exchange across diverse ecosystems, including FLUXNET and long-running regional programs such as OzFlux (Baldocchi et al., 2001; Beringer et al., 2022). Large observatory networks such as NEON further extend this approach through highly standardised tower designs, integrated sensor suites and open data products (Metzger et al., 2019). However, by design, eddy covariance systems integrate processes over footprint scales of tens to hundreds of meters, effectively aggregating fine-scale microclimatic variability into ecosystem-level flux estimates. While recent advances, including camera-based approaches to estimate flux components, have expanded observational capability, these methods still operate at spatial scales that exceed the centimetre- to metre-scale heterogeneity experienced by organisms. Consequently, instrumentation optimised for ecosystem-scale flux integration is not inherently configured to resolve fine-scale microclimatic gradients within structurally heterogeneous environments such as solar farms.

In addition to scale considerations, system architecture introduces further constraints. Sensor combinations are often predefined within specific hardware configurations, limiting flexibility in adapting instrumentation to evolving research questions (Hayibo & Pearce, 2025). In remote deployments, data collection systems frequently require periodic physical access for configuration, data retrieval or maintenance, which becomes increasingly complex as network size grows (Ďud’ák et al., 2023). Long-term autonomous environmental monitoring also imposes constraints on power consumption, storage efficiency and firmware optimisation, necessitating trade-offs in hardware and file system design (Ďud’ák et al., 2023). Importantly, where fine-scale heterogeneity requires dense spatial replication, per-unit hardware cost becomes directly linked to achievable sampling density. Even where individual instruments perform reliably, scaling deployment to tens or hundreds of nodes can constrain study design and limit spatial resolution.

Although open-source platforms have demonstrated that modular systems can reduce per-unit cost while improving flexibility (Ali et al., 2016; Hayibo & Pearce, 2025) ,comparatively fewer studies provide detailed, deployable descriptions that integrate enclosure geometry, long-term field durability, firmware architecture and ecological deployment strategy into cohesive monitoring frameworks. In microclimate research, enclosure design and sensor placement directly influence measurement bias and response time, as airflow, radiation exposure and shielding affect both accuracy and temporal sensitivity. System performance is therefore determined not only by sensor specification, but by the interaction between hardware architecture, mechanical design and deployment context (Maclean et al., 2021). Monitoring platforms intended for structurally heterogeneous solar photovoltaic landscapes must consequently be compact, mechanically stable and capable of resolving fine-scale gradients in radiation, airflow and surface conditions across under-panel, inter-row and edge environments.

In this study, we present the design and implementation of an open, reproducible microclimate monitoring system tailored for fine-scale deployment in heterogeneous landscapes such as photovoltaic (PV) installations. The system integrates temperature and relative humidity sensing, photosynthetically active radiation (PAR) measurement, and ultrasonic wind speed and direction sensing within a compact architecture engineered for field robustness. A central design principle is modularity: sensing modules are decoupled from core data handling and power management, and standard digital communication interfaces (e.g. I²C and 1-Wire) are exposed to enable additional sensors to be incorporated without hardware redesign and with only minor firmware modification. This architecture allows expansion to include variables such as soil moisture, soil temperature, or additional radiation and atmospheric sensors as site-specific research questions evolve, while maintaining a consistent and reproducible platform.

Rather than pursuing comprehensive metrological validation against reference-grade atmospheric instrumentation, this work emphasises transparent documentation of system architecture, electronics design, firmware structure, mechanical housing considerations and build workflow, alongside initial functional testing. The objective is to provide a replicable and adaptable framework that lowers barriers to adoption and supports dense, site-specific microclimate monitoring. By integrating electronics, firmware and enclosure design into a unified and expandable system description, we seek to bridge the gap between proof-of-concept sensor demonstrations and deployable ecological instrumentation.

As renewable energy landscapes continue to expand, scalable tools capable of resolving metre-scale environmental heterogeneity will become increasingly important. Open, modular microclimate systems provide a pathway toward flexible, spatially explicit monitoring of the environments that organisms actually experience.

# 2. System Design Philosophy

The monitoring platform was developed as a fully custom hardware and firmware system guided by five core principles: reproducibility and cost efficiency, distributed node networking with centralised aggregation, modular sensor integration, aerodynamic measurement clarity, and environmental robustness with field configurability.

### 2.1 Reproducible and Cost-Efficient Architecture

The system was implemented using custom-designed printed circuit boards (PCBs) developed in EasyEDA and fabricated via JLCPCB. Component selection prioritised widely available parts to ensure reproducibility and supply stability. Integration of sensing interfaces, power regulation and communication subsystems within compact layouts reduced per-unit cost while maintaining control over signal integrity and environmental performance. This approach supported scalable replication without reliance on proprietary hardware ecosystems.

### 2.2 Distributed Node Network with Centralised Aggregation

The architecture comprised multiple sensor nodes communicating with a central aggregation unit (“mothership”). Nodes function as lightweight sensing units, transmitting measurements wirelessly using the ESP-NOW (WIFI) protocol. Centralised logging at the mothership provides unified data storage and simplified retrieval, reducing direct interaction with individual nodes. This distributed structure supports dense spatial deployment while maintaining manageable data handling and network stability.

### 2.3 Modular Sensor Integration

Modularity was central to the design to accommodate evolving ecological research needs. Standard digital interfaces, including I²C and 1-Wire, were exposed at the hardware level to allow integration of commonly available environmental sensors without redesign of the core architecture. Firmware supports sensor abstraction, enabling new devices to be incorporated through software configuration rather than hardware modification.

The PCB also provides breakout access to multiple analog input channels with selectable excitation voltage levels, enabling compatibility with sensors requiring differing supply and signal conditions. This supports integration of voltage-output and resistive sensors without additional signal-conditioning hardware.

### 2.4 Aerodynamic Measurement Clarity

To preserve measurement accuracy, particularly for ultrasonic wind sensing, the sensing region was designed to minimise geometric obstruction and airflow disturbance. The upper assembly was kept structurally simple to reduce radiative interference and flow distortion that could bias anemometer readings. Electronics, battery systems and wiring were isolated within a lower enclosure to prevent thermal contamination and aerodynamic interference.

### 2.5 Environmental Robustness and Field Configurability

The system was engineered for outdoor deployment, with electronics housed in sealed enclosures to ensure water resistance and mechanical protection. Mechanical components were designed for fused deposition modelling (FDM) 3D printing, allowing rapid fabrication and iterative refinement. Nodes are configured via a local Wi-Fi interface hosted by the mothership, enabling adjustment of measurement intervals, wake schedules and sensor states without physical access or firmware recompilation. This reduces field maintenance burden and supports adaptive deployment strategies.

# 3. System Components (lead with sensors) (TODO)

## 3.1 Instrumentation overview

(Frame outputs, not electronics)

- Air temperature & humidity
- Soil Moisture
- Radiation (PAR)
- Wind speed and direction (ultrasonic)
- Pressure - Others

## 3.2 Logger network (electronics + firmware together)

The logger network is organized around a centralized mothership coordinating multiple distributed sensor nodes for autonomous environmental monitoring under field conditions. The architecture combines low-power duty-cycled operation, synchronized timing, wireless aggregation, and centralized archival in an analysis-ready format.

The mothership serves as network coordinator, time authority, and data logger. A DS3231 real-time clock (RTC) maintains the system reference time used for deployment and timestamping. Wireless communication is implemented using ESP-NOW, a connectionless protocol supported by the ESP32 platform, enabling node discovery, pairing, deployment control, schedule updates, and telemetry reception. Measurements are written to SD-card storage as continuously appended CSV records. A browser-based interface, hosted over a local Wi-Fi access point, provides field configuration of node identity, deployment state, sampling behaviour, and data export.

Each node is an ESP32-based sensing endpoint with a fixed core payload and configurable expansion. The core payload comprises a PAR sensor, an ultrasonic wind anemometer, and an SHTC3 temperature and relative-humidity sensor. In addition, each node provides four auxiliary input channels intended to remain flexible at deployment time. These channels may be configured as analog inputs, I²C interfaces, or mixed-mode combinations within a single node. This approach allows a single hardware platform to support heterogeneous probe sets without redesign.

Node firmware follows a lifecycle model (unpaired, paired, deployed, and stopped/unpaired). During deployment, time and schedule parameters are provisioned by the mothership, after which the node enters periodic acquisition and transmission. Persistent runtime state—including mothership association, deployment status, sampling configuration, and synchronization metadata—is stored in non-volatile memory to support deterministic restart behaviour after power interruption.

At each scheduled acquisition event, the node samples the core sensors and all enabled auxiliary channels, then transmits structured packets to the mothership over ESP-NOW. The mothership timestamps and stores these records together with node and sensor metadata in a unified CSV stream. The resulting system provides a modular, field-deployable framework that integrates synchronized embedded sensing, mixed-interface expansion, wireless telemetry, and centralized data management.

# 3.3 Ultrasonic anemometer (electrical design)

## Time-of-flight principle

The ultrasonic wind subsystem was designed to estimate wind velocity using a differential time-of-flight (ToF) method. Short ultrasonic bursts (~40 kHz) were transmitted between opposing transducers arranged along orthogonal axes. In the intended measurement approach, pulse propagation time is measured in both forward and reverse directions, with wind speed inferred from the difference in travel time (Δt) between opposing paths. The mean travel time provides an estimate of the effective speed of sound along the acoustic path. This differential approach is intended to reduce systematic timing offsets introduced by the electronics and improve robustness to environmental variability such as temperature fluctuations.

In V1, this section should be interpreted as describing the intended operating principle and electrical architecture of the ultrasonic subsystem rather than fully validated measurement performance. Although the transmit and receive chain could be activated during bring-up, commissioning did not yet achieve reliable discrimination of true acoustic arrivals from feedthrough and comparator-trigger artefacts under bench conditions.

## Transmit path

The transmit (TX) chain was designed to generate high-amplitude ultrasonic bursts to provide sufficient acoustic energy across the measurement path. A ~40 kHz carrier signal is generated by the microcontroller using a hardware PWM peripheral. This signal is buffered by a high-speed gate driver, which switches a MOSFET stage powered from a dedicated boost converter targeting approximately 22 V. The resulting voltage swing is intended to drive the ultrasonic transducers with sufficient amplitude to overcome attenuation along the reflector-based measurement path.

Directional excitation of the transducer array is achieved using discrete MOSFET switching stages that connect the selected transducer pair to the transmit driver. These switching elements allow the firmware to sequentially excite orthogonal transducer pairs and reverse the electrical polarity of the drive signal, enabling bidirectional measurements along each axis.

To reduce electrical noise during the receive phase, the high-voltage transmit supply is enabled only during burst emission. The transmit envelope signal generated by the microcontroller is rectified and filtered using a diode–RC network, producing a smoothed control signal that enables the boost converter only during transmit bursts. This strategy was intended to minimise switching noise and reduce interference with the receive electronics.

## Receive path

The receive (RX) chain was designed to convert weak ultrasonic returns into a digital timing signal suitable for precise time measurement. The selected transducer pair is routed through an analog multiplexer that isolates the active receive channel while disconnecting inactive transducers.

The received signal first passes through an input protection network that limits voltage excursions and provides basic filtering. It is then AC-coupled and referenced to a mid-rail virtual ground generated from the system supply. This virtual reference establishes a stable operating point for the subsequent amplification stages.

Two cascaded operational-amplifier stages provide band-limited gain centred near the transmit frequency (~40 kHz). The first stage acts as a low-noise pre-amplifier, while the second provides additional active filtering and gain. This band-pass amplification is intended to improve signal-to-noise ratio by attenuating low-frequency environmental noise and high-frequency electrical interference.

The conditioned waveform is then fed to a high-speed comparator, which converts the analog ultrasonic waveform into a digital timing signal. The comparator threshold is referenced to the mid-rail voltage, allowing the first valid threshold crossing of the received waveform to be detected. The comparator output is routed directly to a hardware timer input on the microcontroller for arrival-time capture.

## Timing and processing

Each measurement cycle begins with the generation of a short ultrasonic burst followed by a defined receive window. A brief blanking interval immediately after transmission is used to suppress false triggering caused by transducer ringing or electrical switching artefacts. During the receive window, the first valid comparator edge is captured by a hardware timer and treated as the time-of-flight measurement.

Measurements are intended to be performed sequentially in both directions along each axis. Under the intended processing model, wind velocity is estimated from the difference between forward and reverse travel times, which removes fixed electronic delays and reduces sensitivity to environmental drift. The mean propagation time provides an additional diagnostic parameter related to the effective speed of sound and overall measurement health.

The limitations identified during V1 commissioning informed a set of proposed refinements for the next hardware revision, including improvements to protection, comparator conditioning, and overall receive-path robustness. Detailed schematics of the transmit and receive circuitry are provided in the Supplementary Materials.

Detailed schematics of the transmit and receive circuitry are provided in the Supplementary Materials.

# 3.4 Mechanical design

The enclosure was developed as a compact, field-ready housing for a custom environmental sensor node designed to measure air temperature and relative humidity, photosynthetically active radiation (PAR), and wind speed and direction using an ultrasonic time-of-flight (ToF) method. In addition to these core measurements, the system supports modular expansion through external sensor ports, allowing additional environmental sensors to be integrated as required for specific monitoring applications. The mechanical design sought to balance two practical constraints: (i) maintaining unobstructed airflow through the wind sensing region to support accurate measurements, and (ii) providing sufficient protected internal volume for the electronics, power supply, and robust cable interfaces suitable for long-term outdoor deployment while supporting flexible sensor integration.

## Head–roof–belly architecture

The housing is organised into three functional components: a head, roof, and belly. The head contains the ultrasonic wind sensing geometry, the roof provides environmental shielding and supports the PAR sensing assembly, and the belly forms a sealed electronics enclosure. This separation keeps cable penetrations and connector hardware away from the wind measurement volume, reducing the likelihood that external protrusions influence local airflow around the acoustic paths. The arrangement also allows the electronics compartment to be opened for servicing without disturbing the wind sensing geometry.

## Overall aerodynamic considerations

The external geometry was designed to minimise turbulence near the ultrasonic measurement region. Smooth external surfaces and gradual transitions were used to reduce sharp flow separation points and to maintain relatively stable airflow conditions through the sensing region. Structural elements (e.g., fasteners and mounting bosses) were positioned outside the primary acoustic pathways where possible. These considerations are important for ultrasonic anemometry because the method relies on precise timing differences between opposing propagation directions; disturbed local flow near the acoustic path can increase variability in time-of-flight estimates.

## Ultrasonic sensing geometry and reflector design

Wind measurements are obtained using ultrasonic time-of-flight between transducers mounted in four angled pods arranged symmetrically around the head. The design uses a compact single-bounce geometry, where an emitted pulse travels upward to the underside of the roof (acting as a reflector) and then returns to the opposing transducer. This approach allows the sensing region to remain relatively open (no struts spanning the measurement volume), while still providing a well-defined and repeatable acoustic path in a compact form factor.

The pod tilt and roof spacing were selected to align the reflected acoustic path so that the nominal reflection occurs near the roof centre and returns to the opposing pod with minimal geometric miss. This symmetry is important because the wind solution is derived from the difference in reciprocal travel times between opposite directions along each axis; maintaining near-identical geometry in both directions reduces systematic offsets and supports stable calibration. The pod arrangement also elevates the acoustic paths above nearby structural features and reduces the likelihood of obstruction by roof mounts or the enclosure rim.

Each pod incorporates a stepped bore that sets transducer seating depth and helps maintain consistent alignment between builds. While sealing features are included for weather resistance, the primary measurement-driven design choice is the repeatability of transducer positioning and the resulting stability of the acoustic path length and reflection geometry.

## Roof and PAR assembly

The roof provides rain protection and houses the PAR sensor and diffuser assembly. A circular diffuser seat and PCB mounting bosses are integrated into the roof to position the PAR optics and sensor board consistently. To avoid introducing additional openings or external cable runs near the wind sensing region, the PAR I²C cable is routed internally through a dedicated channel integrated into one of the roof standoffs, passing from the roof cavity down into the belly where the main electronics are housed.

In addition to its protective role, the underside of the roof acts as the reflective surface required for the single-bounce ultrasonic ToF path, linking the mechanical roof geometry directly to the wind sensing method.

## Belly (electronics enclosure)

The belly encloses the custom node PCB, battery, and internal wiring while maintaining serviceability and weather resistance. A continuous sealing groove around the rim accommodates a silicone cord gasket, providing a repeatable seal while allowing the enclosure to be reopened for maintenance. Cable penetrations for external sensors are implemented on localised flat mounting pads to support standard glands/connectors and to maintain adequate wall thickness around penetrations for mechanical strength.

# 4. Materials and Methods (TODO)

## 4.1 Bill of materials

(High-level table in paper)
(Full BOM in supplement)

## 4.2 Build and assembly

- Electronics assembly
- Mechanical assembly
- Print orientations
- Sealing steps

## 4.3 Firmware deployment

- Flashing
- Pairing
- Deployment
- Configuration

# 4.4 Bring-up and commissioning workflow

System bring-up was formalised as a staged commissioning workflow conducted prior to ecological deployment. Its purpose was to verify that each node and the mothership could function as an integrated measurement system under realistic field conditions. In V1, this process also served as an iterative fault-isolation step, because early boards exposed several hardware and integration issues that required correction before reliable operation was achieved. Bring-up therefore provided a practical basis for assessing deployment readiness while clarifying subsystem-level failures and limitations.

# 4.4.1 Bring-up goals

Bring-up was designed around five practical goals:

1. Confirm electrical and communication integrity of each assembled node.
2. Verify that core sensors and interfaces returned plausible, stable outputs where functional.
3. Confirm reliable node discovery, pairing, and deployment through the mothership interface.
4. Verify scheduled wake/synchronisation behaviour and continuity of data logging.
5. Establish a consistent basis for deciding whether a unit was ready for further testing or deployment.

# 4.4.2 Staged procedure

Bring-up was conducted in four stages.

Stage A: Hardware and power integrity check

- Visual inspection of solder joints, connector seating, enclosure seals, and cable routing.
- Verification of supply rails and regulator behaviour under expected load.
- Confirmation of microcontroller boot behaviour, serial output, and reset stability.
- Isolation of abnormal current draw, thermal hotspots, or rail collapse where present.

# Stage B: Sensor and interface verification

- I2C bus scans and device-detection checks for connected digital sensors.
- Analog channel checks for expected range and response direction, including soil channels where fitted.
- Functional response checks using simple environmental stimuli, such as hand shading for PAR response and ambient thermal change for air temperature and humidity.
- For the ultrasonic wind subsystem, confirmation of basic acquisition-path activity and timing repeatability under bench conditions, while recognising that full acoustic discrimination remained unresolved in V1.

# Stage C: Network bring-up and control-path validation

- Verification of node discovery through the mothership dashboard.
- Verification of pairing and deployment transitions across node lifecycle states.
- Confirmation that schedule commands, including wake and synchronisation intervals, propagated correctly and were retained after reset.
- Time-synchronisation checks between the mothership and nodes.
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

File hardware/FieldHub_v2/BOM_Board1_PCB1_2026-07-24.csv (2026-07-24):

No. | Quantity | Comment | Designator | Footprint | Value | Manufacturer Part | Manufacturer | Supplier Part | Supplier | LCSC Stock | LCSC Price | JLCPCB Stock | JLCPCB Price | Device | Unique ID
1 | 2 | 1uF | 1uf1,C152 | C0402 | 1uF | CL05A105KP5NNNC | SAMSUNG(三星) | C14445 | LCSC |  |  | 1729936 | 0.0019 | CL05A105KP5NNNC | gge143,gge356
2 | 16 | Test-Point | 1V8,3V4,4V,ALM2,AON2,BATT1,M_VBUS,PWRK,RST,RX2,STS,TX2,USB_BOOT,USB_DM,USB_DP,VSYS1 | Test-Point-0.5mm |  |  |  |  |  | 695 | 0.0822 |  |  | Test-Point | gge274,gge275_1,gge276,gge277_1,gge278_1,gge361,gge362,gge363,gge364,gge365,gge366,gge367,gge368,gge369,gge370,gge372
3 | 1 | CR1220-2 | B2 | BAT-SMD_CR1220-2 |  | CR1220-2 | QIJEY | C70381 | LCSC |  |  | 22145 | 0.0359 | CR1220-2 | gge25_1
4 | 1 | 100uF | C1 | C1206 | 100uF | GRM31CR61A107MEA8L | muRata(村田) | C883598 | LCSC |  |  | 229907 | 0.0758 | GRM31CR61A107MEA8L | gge371
5 | 27 | 100nF | C14,C16,C61,C77,C78,C81,C82,C87,C88,C97,C98,C126,C128,C129,C130,C133,C135,C137,C142,C143,C144,C145,C146,C147,C148,C149,C153 | C0402 | 100nF | CL05B104KO5NNNC | SAMSUNG(三星) | C1525 | LCSC |  |  | 47520862 | 0.0008 | CL05B104KO5NNNC | gge15_1,gge16_1,gge27_1,gge29_1,gge29_2,gge29_4,gge31_1,gge31_2,gge33_1,gge43_2,gge45_2,gge129_2,gge129_3,gge141,gge141_2,gge172,gge172_1,gge172_2,gge172_3,gge172_4,gge172_5,gge172_6,gge172_7,gge172_8,gge172_9,gge172_10,gge172_11
6 | 13 | 10uF | C15,C59,C79,C80,C83,C84,C89,C90,C125,C131,C134,C136,C151 | C0603 | 10uF | CL10A106KP8NNNC | SAMSUNG(三星) | C19702 | LCSC |  |  | 15861216 | 0.0061 | CL10A106KP8NNNC | gge13_1,gge14_1,gge26_1,gge26_2,gge26_3,gge28_1,gge28_3,gge34_1,gge34_2,gge42_2,gge44_2,gge139,gge355
7 | 2 | 470uF | C69,C150 | CAP-SMD_BD6.3-L6.6-W6.6-LS7.6-RD | 470uF | RVT1C471M0607 | ROQANG(容强) | C2977552 | LCSC |  |  | 201977 | 0.0103 | RVT1C471M0607 | gge170,gge354
8 | 1 | 47nF | C127 | C0603 | 47nF | CL10B473KB8NNNC | SAMSUNG(三星) | C1622 | LCSC |  |  | 1301778 | 0.0013 | CL10B473KB8NNNC | gge41
9 | 1 | 47uF | C132 | C1206 | 47uF | TCC1206X5R476M100HT | CCTC(三环) | C5448950 | LCSC |  |  | 32930 | 0.0165 | TCC1206X5R476M100HT | gge326
10 | 3 | 22uF | C138,C139,C140 | C0603 | 22uF | CL10A226MP8NUNE | SAMSUNG(三星) | C86295 | LCSC |  |  | 1826152 | 0.0151 | CL10A226MP8NUNE | gge335,gge336,gge337
11 | 1 | 4.7pF | C141 | C0402 | 4.7pF | CC0402BRNPO9BN4R7 | YAGEO(国巨) | C325453 | LCSC |  |  | 221165 | 0.0008 | CC0402BRNPO9BN4R7 | gge340
12 | 1 | 33pF | C154 | C0402 | 33pF | FCC0402N330J500AT | FOJAN(富捷) | C5137486 | LCSC |  |  | 3970542 | 0.001 | FCC0402N330J500AT | gge357
13 | 1 | 10pF | C155 | C0402 | 10pF | CC0402JRNPO9BN100 | YAGEO(国巨) | C106199 | LCSC |  |  | 909172 | 0.001 | CC0402JRNPO9BN100 | gge358
14 | 1 | 1N4148W | D1 | SOD-123_L2.7-W1.6-LS3.7-FD |  | 1N4148W | HXY MOSFET(华轩阳电子) | C5345962 | LCSC |  |  | 595913 | 0.0014 | 1N4148W_C5345962 | gge320
15 | 1 | ESDA6V1W5 | D2 | SC-70-5_L2.1-W1.3-P0.65-LS2.1-BR |  | ESDA6V1W5 | ST(意法半导体) | C48677 | LCSC |  |  | 16996 | 0.0223 | ESDA6V1W5 | gge353
16 | 1 | SMAJ5.0A | D3 | SMA_L4.3-W2.6-LS5.1-RD |  | SMAJ5.0A | TDSEMIC(拓电半导体) | C46956328 | LCSC |  |  | 12148 | 0.0052 | SMAJ5.0A_C46956328 | gge359
17 | 1 | ESD9L5.0ST5G | D4 | SOD-923_L0.8-W0.6-LS1.0-RD |  | ESD9L5.0ST5G | onsemi(安森美) | C82326 | LCSC |  |  | 149957 | 0.0069 | ESD9L5.0ST5G | gge360
18 | 1 | 33Ω | F1 | RES-ARRAY-SMD_0404-4P-L1.0-W1.0-BL | 33Ω | YC122-JR-0733RL | YAGEO(国巨) | C695180 | LCSC |  |  | 343 | 0.0006 | YC122-JR-0733RL | gge192
19 | 1 | 4.7kΩ | F2 | RES-ARRAY-SMD_0404-4P-L1.0-W1.0-BL | 4.7kΩ | YC122-JR-074K7L | YAGEO(国巨) | C695194 | LCSC |  |  | 10 | 0.0005 | YC122-JR-074K7L | gge325
20 | 1 | 1812L050PR | F5 | F1812 |  | 1812L050PR | Littelfuse(美国力特) | C151169 | LCSC |  |  | 2960 | 0.0097 | 1812L050PR | gge20_1
21 | 1 | 6GHz | JP1 | RF-SMD_FRF05002-JSS103M | 6GHz | U.FL-R-SMT-1(80) | HRS(广濑) | C88374 | LCSC |  |  | 228507 | 0.0151 | U.FL-R-SMT-1(80)_C88374 | gge334
22 | 1 | 1.5uH | L1 | IND-SMD_L4.4-W4.1_PCR0420 | 1.5uH | PCR0420-1R5-M | JIERR(捷而瑞) | C53896855 | LCSC |  |  | 4678 | 0.014 | PCR0420-1R5-M | gge333
23 | 2 | KT-0603G | LED3,LED8 | LED0603-RD |  | KT-0603G | KENTO | C12624 | LCSC |  |  | 437493 | 0.0019 | KT-0603G | gge18_1,gge18_2
24 | 1 | KT-0603R | LED7 | LED0603-RD |  | KT-0603R | KENTO | C2286 | LCSC |  |  | 7050439 | 0.0011 | KT-0603R | gge17_2
25 | 2 | NCD0603B1 | LED9,LED10 | LED0603-RD |  | NCD0603B1 | 国星光电 | C84266 | LCSC |  |  | 935706 | 0.0026 | NCD0603B1 | gge327,gge327_1
26 | 2 | AO3407A | Q2,Q37 | SOT-23-3_L2.9-W1.6-P1.90-LS2.8-BR |  | AO3407A | AOS | C15155 | LCSC |  |  | 122773 | 0.0145 | AO3407A_C15155 | gge6,gge6_1
27 | 6 | 2N7002 | Q3,Q4,Q40,Q41,Q42,Q43 | SOT-23-3_L2.9-W1.3-P1.90-LS2.4-BR |  | 2N7002 | CBI(创基) | C51315010 | LCSC |  |  | 1435 | 0.0024 | 2N7002_C51315010 | gge24,gge24_1,gge24_2,gge36,gge36_1,gge36_2
28 | 3 | MMBT3904 | Q14,Q15,Q44 | SOT-23-3_L2.9-W1.3-P1.90-LS2.4-BR |  | MMBT3904 | CCX(晁禾) | C51953474 | LCSC |  |  | 176381 | 0.0012 | MMBT3904_C51953474 | gge171_1,gge171_3,gge171_4
29 | 1 | MMBT3904(RANGE:100-300) | Q39 | SOT-23-3_L2.9-W1.3-P1.90-LS2.4-BR |  | MMBT3904(RANGE:100-300) | CJ(江苏长电/长晶) | C20526 | LCSC |  |  | 773752 | 0.0019 | MMBT3904(RANGE:100-300) | gge167_2
30 | 8 | 22Ω | R1,R2,R3,R176,R177,R178,RN6,RN7 | R0402 | 22Ω | FRC0402J220 TS | FOJAN(富捷) | C2906914 | LCSC |  |  | 354864 | 0.0003 | FRC0402J220 TS | gge191,gge191_1,gge322,gge323,gge324,gge350_0,gge351_0,gge352_0
31 | 10 | 10kΩ | R4,R5,R6,R7,R55,R56,R91,R92,R175,R187 | R0402 | 10kΩ | 0402WGF1002TCE | UNI-ROYAL(厚声) | C25744 | LCSC |  |  | 9856 | 0.0003 | 0402WGF1002TCE | gge142,gge146,gge146_1,gge193,gge194,gge342,gge375,gge376,gge377,gge378
32 | 18 | 100kΩ | R10,R59,R96,R97,R153,R165,R167,R168,R169,R170,R171,R172,R173,R174,R184,R185,R189,R192 | R0402 | 100kΩ | 0402WGF1003TCE | UNI-ROYAL(厚声) | C25741 | LCSC |  |  | 65041 | 0.0003 | 0402WGF1003TCE | gge37,gge37_1,gge37_5,gge37_6,gge37_7,gge57_2,gge57_5,gge63,gge63_1,gge63_2,gge63_3,gge63_4,gge63_5,gge63_6,gge329,gge339,gge341,gge344
33 | 2 | 100Ω | R12,R190 | R0402 | 100Ω | 0402WGF1000TCE | UNI-ROYAL(厚声) | C25076 | LCSC |  |  | 1058027 | 0.0003 | 0402WGF1000TCE | gge40,gge343
34 | 6 | 2.2kΩ | R62,R78,R159,R181,R182,R195 | R0402 | 2.2kΩ | 0402WGF2201TCE | UNI-ROYAL(厚声) | C25879 | LCSC |  |  | 1401625 | 0.0003 | 0402WGF2201TCE | gge11_1,gge12_1,gge12_2,gge208_1,gge208_2,gge208_3
35 | 2 | 47kΩ | R68,R194 | R0402 | 47kΩ | FRC0402F4702TS | FOJAN(富捷) | C2906872 | LCSC |  |  | 999859 | 0.0004 | FRC0402F4702TS | gge168,gge349
36 | 1 | 3.6kΩ | R81 | R0402 | 3.6kΩ | RC0402FR-073K6L | YAGEO(国巨) | C137990 | LCSC |  |  | 71700 | 0.0002 | RC0402FR-073K6L | gge9_1
37 | 2 | 1MΩ | R154,R166 | R0402 | 1MΩ | 0402WGF1004TCE | UNI-ROYAL(厚声) | C26083 | LCSC |  |  | 925536 | 0.0011 | 0402WGF1004TCE | gge169_1,gge169_3
38 | 1 | 220kΩ | R157 | R0603 | 220kΩ | 0603WAF2203T5E | UNI-ROYAL(厚声) | C22961 | LCSC |  |  | 2031204 | 0.0005 | 0603WAF2203T5E | gge272
39 | 1 | 100kΩ | R158 | R0603 | 100kΩ | 0603WAF1003T5E | UNI-ROYAL(厚声) | C25803 | LCSC |  |  | 7450568 | 0.0004 | 0603WAF1003T5E | gge271
40 | 2 | 5.1kΩ | R179,R180 | R0402 | 5.1kΩ | FRC0402F5101TS | FOJAN(富捷) | C2906874 | LCSC |  |  | 2016102 | 0.0005 | FRC0402F5101TS | gge189_3,gge189_4
41 | 1 | 680kΩ | R183 | R0402 | 680kΩ | FRC0402F6803TS | FOJAN(富捷) | C2909377 | LCSC |  |  | 568994 | 0.0004 | FRC0402F6803TS | gge338
42 | 1 | 100Ω | R188 | R0402 | 100Ω | FRC0402F1000TS | FOJAN(富捷) | C2906860 | LCSC |  |  | 3017291 | 0.0004 | FRC0402F1000TS | gge328
43 | 1 | 4.7kΩ | R193 | R0402 | 4.7kΩ | FRC0402J472 TS | FOJAN(富捷) | C2906941 | LCSC |  |  | 9420195 | 0.0003 | FRC0402J472 TS | gge348
44 | 1 | MICRO SIM 7P H1.35 | SIM1 | SIM-SMD_MICRO-SIM-7P-H1.35 |  | MICRO SIM 7P H1.35 | SHOU HAN(首韩) | C7529381 | LCSC |  |  | 15032 | 0.0325 | MICRO SIM 7P H1.35 | gge330
45 | 2 | HX-3x6x2.5-X SMD tact Switch | SW2,SW3 | SW-SMD_HX-3X6X2.5-X |  | HX-3x6x2.5-X SMD tact Switch | hanxia(韩下) | C49234125 | LCSC |  |  | 42755 | 0.0025 | HX-3x6x2.5-X SMD tact Switch | gge144,gge147
46 | 2 | MST-12D18G2 SMD Slide Switch | SW9,SW10 | SW-SMD_3P-L9.1-W3.5-P2.50_MST-12D18G2 |  | MST-12D18G2 SMD Slide Switch | SHOU HAN(首韩) | C49023765 | LCSC |  |  | 7998 | 0.012 | MST-12D18G2 SMD Slide Switch | gge317,gge317_1
47 | 1 | TF-CARD H1.8 SY | TF1 | TF-SMD_TF-012 |  | TF-CARD H1.8 SY | SHOU HAN(首韩) | C7529391 | LCSC |  |  | 17213 | 0.0077 | TF-CARD H1.8 SY | gge321
48 | 1 | CUSTOM THROUGH HOLES 4P X 2.54MM | U1 | CUSTOM THROUGH HOLES 4P X 2.54MM |  |  |  |  |  |  |  |  |  | CUSTOM THROUGH HOLES 4P X 2.54MM | gge373
49 | 1 | RDC10320RB | U2 | CUSTOM THROUGH HOLES 1X6P X 2.54MM |  | RDC10320RB |  | C351182 | LCSC |  |  | 1766 | 0.3015 | CUSTOM THROUGH HOLES 1X6P X 2.54MM | gge374
50 | 1 | 1812L110PR | U7 | FUSE-SMD_L4.7-W3.4 |  | 1812L110PR | Littelfuse(美国力特) | C163516 | LCSC |  |  | 2334 | 0.0056 | 1812L110PR | gge22
51 | 1 | CN3163 | U23 | ESOP-8_L4.9-W3.9-P1.27-LS6.0-BL-EP |  | CN3163 | CONSONANCE(上海如韵) | C559031 | LCSC |  |  | 17568 | 0.0385 | CN3163 | gge4_1
52 | 1 | CH340C | U38 | SOP-16_L10.0-W3.9-P1.27-LS6.0-BL |  | CH340C | WCH(南京沁恒) | C84681 | LCSC |  |  | 41101 | 0.0866 | CH340C | gge186
53 | 1 | ESP32-WROOM-32D-N4 | U45 | WIFIM-SMD_39P-L25.5-W18.0-P1.27-BL |  | ESP32-WROOM-32D-N4 | ESPRESSIF(乐鑫) | C473012 | LCSC |  |  | 6362 | 0.559 | ESP32-WROOM-32D-N4 | gge264
54 | 2 | DB301V-3.5-2P-GN-S | U47,U48 | CONN-TH_DB301V-3.5-2P-GN |  | DB301V-3.5-2P-GN-S | DORABO(地博电气) | C695629 | LCSC |  |  | 255070 | 0.014 | DB301V-3.5-2P-GN-S | gge270,gge270_1
55 | 1 | DS3231MZ+TRL | U49 | SOIC-8_L4.9-W3.9-P1.27-LS6.0-BL |  | DS3231MZ+TRL | ADI(亚德诺)/MAXIM(美信) | C107410 | LCSC |  |  | 9348 | 0.4792 | DS3231MZ+TRL | gge7_1
56 | 1 | AP2112K-3.3TRG1 | U50 | SOT-25-5_L2.9-W1.6-P0.95-LS2.8-BL |  | AP2112K-3.3TRG1 | DIODES(美台) | C51118 | LCSC |  |  | 23673 | 0.025 | AP2112K-3.3TRG1 | gge1_2
57 | 1 | TPL720F33-3TR | U51 | SOT-23-3_L2.9-W1.6-P1.90-LS2.8-BR |  | TPL720F33-3TR | 3PEAK(思瑞浦) | C2842389 | LCSC |  |  | 533 | 0.0164 | TPL720F33-3TR | gge23_1
58 | 1 | SN74LVC2G74DCUR | U52 | US-8_L2.4-W2.1-P0.50-LS3.2-BR |  | SN74LVC2G74DCUR | TI(德州仪器) | C7851 | LCSC |  |  | 354 | 0.052 | SN74LVC2G74DCUR_C7851 | gge318
59 | 1 | K2-1807SA-A4DW-06 | U53 | KEY-SMD_L4.0-W2.9-LS4.8 |  | K2-1807SA-A4DW-06 | 韩国韩荣 | C128943 | LCSC |  |  | 1455 | 0.0122 | K2-1807SA-A4DW-06 | gge319
60 | 1 | TYPE-C 16PLT-H6.5 | U54 | USB-C-SMD_SOUHAN_TYPE-C-16PLT-H6.5 |  | TYPE-C 16PLT-H6.5 | SHOU HAN(首韩) | C3151748 | LCSC |  |  | 16115 | 0.0541 | TYPE-C 16PLT-H6.5 | gge205_1
61 | 1 | MF-MSMF050-2 | U55 | F1812 |  | MF-MSMF050-2 | BOURNS | C17313 | LCSC |  |  | 31481 | 0.0098 | MF-MSMF050-2 | gge199_1
62 | 1 | TPD2EUSB30DRTR | U56 | SOT-723_L1.2-W0.8-P0.80-LS1.2-BR |  | TPD2EUSB30DRTR | TECH PUBLIC(台舟) | C5182099 | LCSC |  |  | 11 | 0.0289 | TPD2EUSB30DRTR_C5182099 | gge187_1
63 | 1 | A7670G | U58 | LGA-124_L24.0-W24.0-P1.0-A7670C-LASS |  | A7670G | SIMCOM(芯讯通无线科技) | C5846957 | LCSC |  |  | 253 | 1.7008 | A7670G | gge331
64 | 1 | TPS63020DSJR | U59 | VSON-14_L4.0-W3.0-P0.50-BL-EP_TI_DSJ |  | TPS63020DSJR | TI(德州仪器) | C15483 | LCSC |  |  | 9568 | 0.132 | TPS63020DSJR | gge332
65 | 3 | SN74LVC1T45DCKR | U60,U61,U62 | SC-70-6_L2.2-W1.3-P0.65-LS2.2-BR |  | SN74LVC1T45DCKR | TI(德州仪器) | C9382 | LCSC |  |  | 11950 | 0.0331 | SN74LVC1T45DCKR | gge345,gge346,gge347

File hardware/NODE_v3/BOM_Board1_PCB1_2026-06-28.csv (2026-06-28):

No. | Quantity | Comment | Designator | Footprint | Value | Manufacturer Part | Manufacturer | Supplier Part | Supplier | LCSC Stock | LCSC Price | JLCPCB Stock | JLCPCB Price | Device | Unique ID
1 | 1 | 1uF | 1uf | C0402 | 1uF | CL05A105KP5NNNC | SAMSUNG(三星) | C14445 | LCSC |  |  | 1167372 | 0.001 | CL05A105KP5NNNC | gge143
2 | 27 | Test-Point | 3V3,5V,22V,A1_V,A2_V,ALM,AON,BATT,EN_22,ESP_PWR,GND,GND1,GND2,PWM_5v,RX,RX_EN,RX_IN,SCL,SDA,TOF,TP3,TP4,TX_22_EN,TX_pulse,TX_PWM,VREF,VSYS | Test-Point-0.5mm |  |  |  |  |  |  | 0.0733 |  |  | Test-Point | gge226,gge227,gge262,gge263,gge273,gge274,gge275,gge276,gge277,gge278,gge279,gge280,gge281,gge282,gge283,gge284,gge285,gge286,gge295,gge296,gge297,gge298,gge304,gge308,gge309,gge314,gge315
3 | 1 | CR1220-2 | B1 | BAT-SMD_CR1220-2 |  | CR1220-2 | QIJEY | C70381 | LCSC |  |  | 15915 | 0.0358 | CR1220-2 | gge25
4 | 1 | 100uF | C1 | C1210 | 100uF | GRM32ER60J107ME20L | muRata(村田) | C88154 | LCSC |  |  | 18168 | 0.0718 | GRM32ER60J107ME20L_C88154 | gge323
5 | 7 | 1uF | C2,C3,C52,C60,C100,C106,C114 | C0603 | 1uF | CL10A105KB8NNNC | SAMSUNG(三星) | C15849 | LCSC |  |  | 6519446 | 0.0069 | CL10A105KB8NNNC | gge133_1,gge140,gge147_1,gge207,gge207_0,gge215,gge324
6 | 1 | 4.7uF | C4 | C0402 | 4.7uF | TCC0402X5R475M6R3AT | CCTC(三环) | C380302 | LCSC |  |  | 60907 | 0.0019 | TCC0402X5R475M6R3AT | gge327
7 | 37 | 100nF | C5,C6,C8,C10,C11,C12,C15,C16,C18,C19,C61,C71,C72,C75,C78,C81,C83,C87,C88,C93,C96,C97,C98,C99,C101,C104,C110,C111,C119,C120,C121,C122,C123,C128,C129,C130,C131 | C0402 | 100nF | CL05B104KO5NNNC | SAMSUNG(三星) | C1525 | LCSC |  |  | 32414840 | 0.0012 | CL05B104KO5NNNC | gge15_1,gge16_1,gge27,gge27_2,gge29,gge29_1,gge29_2,gge29_3,gge31,gge31_1,gge31_2,gge31_3,gge31_4,gge31_5,gge31_7,gge31_8,gge31_9,gge31_10,gge31_11,gge33,gge43_1,gge45_1,gge45_2,gge47_1,gge50_1,gge61_1,gge129_2,gge129_3,gge130_1,gge131_1,gge141,gge141_2,gge145,gge157,gge158,gge172,gge172_5
8 | 11 | 10uF | C7,C9,C13,C17,C59,C73,C74,C89,C90,C95,C125 | C0603 | 10uF | CL10A106KP8NNNC | SAMSUNG(三星) | C19702 | LCSC |  |  | 5956371 | 0.0072 | CL10A106KP8NNNC | gge13_1,gge14_1,gge26,gge26_1,gge28,gge28_1,gge28_2,gge34,gge42_1,gge44_1,gge139
9 | 1 | 47nF | C14 | C0603 | 47nF | CL10B473KB8NNNC | SAMSUNG(三星) | C1622 | LCSC |  |  | 1179839 | 0.0013 | CL10B473KB8NNNC | gge41
10 | 1 | 470uF | C69 | CAP-SMD_BD6.3-L6.6-W6.6-LS7.6-RD | 470uF | RVT1C471M0607 | ROQANG(容强) | C2977552 | LCSC |  |  | 164988 | 0.0097 | RVT1C471M0607 | gge170
11 | 2 | 22uF | C76,C77 | C0603 | 22uF | CL10A226MP8NUNE | SAMSUNG(三星) | C86295 | LCSC |  |  | 2043847 | 0.0123 | CL10A226MP8NUNE | gge48_1,gge49_1
12 | 2 | 100nF | C86,C112 | C0402 | 100nF | GRM155R71H104KE14D | muRata(村田) | C77020 | LCSC |  |  | 59078 | 0.0023 | GRM155R71H104KE14D | gge31_6,gge175
13 | 1 | 22uF | C94 | C0603 | 22uF | CL10A226MQ8NRNC | SAMSUNG(三星) | C59461 | LCSC |  |  | 4501118 | 0.0036 | CL10A226MQ8NRNC | gge166_1
14 | 3 | 1nF | C102,C107,C109 | C0402 | 1nF | CL05B102KB5NNNC | SAMSUNG(三星) | C14442 | LCSC |  |  | 350723 | 0.0004 | CL05B102KB5NNNC | gge209,gge216,gge220
15 | 1 | 220pF | C103 | C0402 | 220pF | 0402B221K500NT | FH(风华) | C1530 | LCSC |  |  | 824100 | 0.0003 | 0402B221K500NT | gge211
16 | 2 | 150pF | C105,C108 | C0402 | 150pF | 0402B151K500NT | FH(风华) | C1527 | LCSC |  |  | 192350 | 0.0007 | 0402B151K500NT | gge214,gge219
17 | 1 | 1uF | C113 | C0805 | 1uF | CC0805KKX7R9BB105 | YAGEO(国巨) | C91185 | LCSC |  |  | 5715 | 0.0068 | CC0805KKX7R9BB105 | gge235
18 | 4 | 1nF | C115,C116,C117,C118 | C0402 | 1nF | CC0402X7R50V102KN | TORCH(火炬) | C53084512 | LCSC |  |  | 27375 | 0.0006 | CC0402X7R50V102KN | gge139_1,gge140_1,gge141_1,gge142_1
19 | 5 | B2B-PH-SM4-TB(LF)(SN) | CN11,CN12,CN13,CN14,edaimagecopyoccupy | CONN-SMD_B2B-PH-SM4-TB-LF-SN |  | B2B-PH-SM4-TB(LF)(SN) | JST | C160352 | LCSC |  |  | 173 | 0.0532 | B2B-PH-SM4-TB(LF)(SN) | gge67_4,gge67_5,gge67_6,gge67_7,gge332
20 | 6 | BM04B-SRSS-TB(LF)(SN) | CN15,CN16,CN17,CN18,CN19,CN20 | CONN-SMD_BM04B-SRSS-TB |  | BM04B-SRSS-TB(LF)(SN) | JST | C160390 | LCSC |  |  | 32508 | 0.0342 | BM04B-SRSS-TB(LF)(SN) | gge159,gge159_2,gge159_3,gge159_4,gge159_5,gge159_6
21 | 1 | SS34 | D1 | SMA_L4.3-W2.6-LS5.1-RD |  | SS34 | Hangyu(航昱微) | C52023881 | LCSC |  |  | 53453 | 0.0034 | SS34_C52023881 | gge334
22 | 2 | SS14 | D6,D7 | SMA_L4.4-W2.6-LS5.0-RD |  | SS14 | HT(金誉) | C48782961 | LCSC |  |  | 5563 | 0.0023 | SS14_C48782961 | gge53_1,gge54_1
23 | 2 | BAV99 | D8,D9 | SOT-23-3_L2.9-W1.3-P1.90-LS2.4-BR |  | BAV99 | baocheng(宝乘) | C51898307 | LCSC |  |  | 26368 | 0.0016 | BAV99_C51898307 | gge210,gge221
24 | 5 | BZT52C15 | D10,D11,D12,D13,D14 | SOD-123_L2.7-W1.6-LS3.7-RD-1 |  | BZT52C15 | YONGYUTAI(永裕泰) | C2891782 | LCSC |  |  | 19255 | 0.0016 | BZT52C15_C2891782 | gge233,gge236,gge246,gge254,gge261
25 | 4 | SS14 | D15,D16,D17,D18 | SMA_L4.3-W2.6-LS5.0-RD |  | SS14 | YONGYUTAI(永裕泰) | C47147601 | LCSC |  |  | 106554 | 0.0016 | SS14_C47147601 | gge182_1,gge182_2,gge182_3,gge182_4
26 | 2 | BZT52C12S | D19,D20 | SOD-323_L1.6-W1.3-LS2.7-RD |  | BZT52C12S | TWGMC(迪嘉) | C727035 | LCSC |  |  | 6212 | 0.002 | BZT52C12S_C727035 | gge173_1,gge173_2
27 | 5 | 33Ω | F1,F4,F6,F7,F8 | RES-ARRAY-SMD_0404-4P-L1.0-W1.0-BL | 33Ω | YC122-JR-0733RL | YAGEO(国巨) | C695180 | LCSC |  |  | 404 | 0.0005 | YC122-JR-0733RL | gge192,gge214_1,gge215_1,gge216_1,gge217_1
28 | 1 | 1812L050PR | F5 | F1812 |  | 1812L050PR | Littelfuse(美国力特) | C151169 | LCSC |  |  | 3742 | 0.0096 | 1812L050PR | gge20_1
29 | 1 | 2.54-2*3P立贴针 | H1 | HDR-SMD_6P-P2.54-V-M-R2-C5-S7.4 |  | 2.54-2*3P立贴针 | BOOMELE(博穆精密) | C192301 | LCSC |  |  | 5650 | 0.0071 | 2.54-2*3P立贴针 | gge269
30 | 1 | 22uH | L1 | IND-SMD_L5.6-W5.2_MST0530H-150M | 22uH | DH0530H-220M | DH(德鸿感应) | C41406986 | LCSC |  |  | 7249 | 0.0123 | DH0530H-220M | gge322
31 | 1 | 22uH | L4 | IND-SMD_L4.6-W4.2_SMMS0420 | 22uH | SMMS0420-220M | SXN(顺翔诺) | C2894720 | LCSC |  |  | 13463 | 0.0245 | SMMS0420-220M | gge46_1
32 | 1 | 10uH | L6 | IND-SMD_L7.4-W6.6 | 10uH | CKST0603-10uH/M | CENKER(岑科) | C3002639 | LCSC |  |  | 7810 | 0.0203 | CKST0603-10uH/M | gge157_1
33 | 1 | KT-0603G | LED3 | LED0603-RD |  | KT-0603G | KENTO | C12624 | LCSC |  |  | 353051 | 0.0019 | KT-0603G | gge18_1
34 | 2 | KT-0603R | LED7,LED8 | LED0603-RD |  | KT-0603R | KENTO | C2286 | LCSC |  |  | 8345824 | 0.0011 | KT-0603R | gge17_2,gge17_3
35 | 2 | AO3407A | Q2,Q37 | SOT-23-3_L2.9-W1.6-P1.90-LS2.8-BR |  | AO3407A | AOS | C15155 | LCSC |  |  | 157797 | 0.0144 | AO3407A_C15155 | gge6,gge6_1
36 | 8 | 2N7002 | Q3,Q4,Q21,Q22,Q28,Q31,Q34,Q39 | SOT-23-3_L2.9-W1.3-P1.90-LS2.4-BR |  | 2N7002 | CBI(创基) | C51315010 | LCSC |  |  | 2849 | 0.0011 | 2N7002_C51315010 | gge24,gge24_1,gge36,gge231,gge232,gge242,gge251,gge256
37 | 4 | MMBT3904 | Q14,Q15,Q19,Q36 | SOT-23-3_L2.9-W1.3-P1.90-LS2.4-BR |  | MMBT3904 | CCX(晁禾) | C51953474 | LCSC |  |  | 10563 | 0.001 | MMBT3904_C51953474 | gge171_3,gge171_4,gge171_5,gge171_6
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

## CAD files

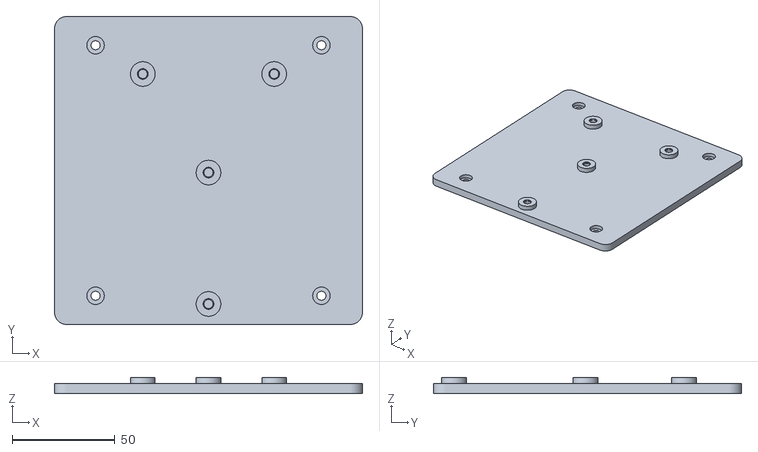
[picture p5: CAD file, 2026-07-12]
hardware/sensor_housings/node_box_sensor_deck/stl/node_box_sensor_deck.stl
150.0 x 150.0 x 8.00

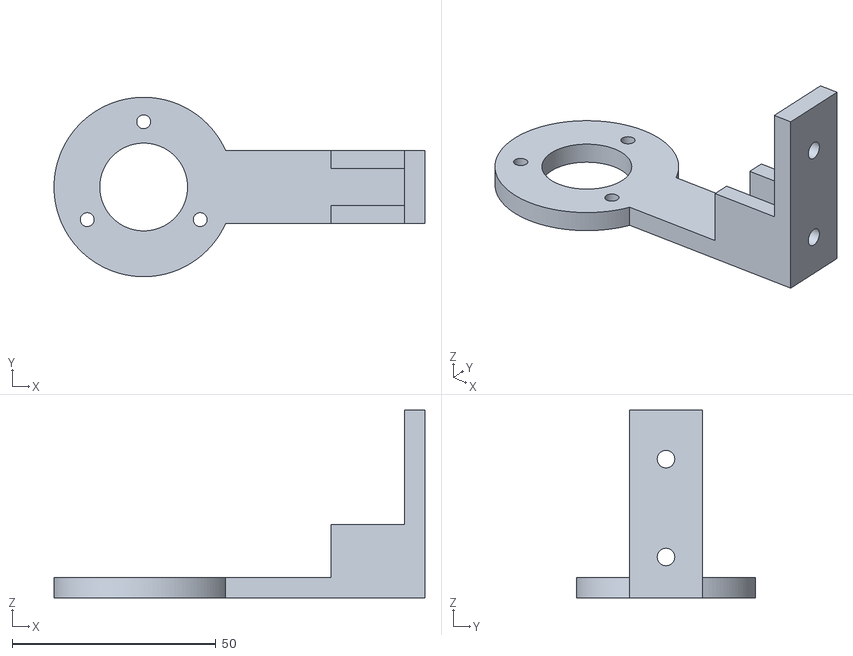
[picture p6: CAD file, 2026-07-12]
hardware/sensor_housings/sht40_stevenson/stl/sht40_right_angle_bracket_adapter.stl
91.0 x 44.0 x 46.0

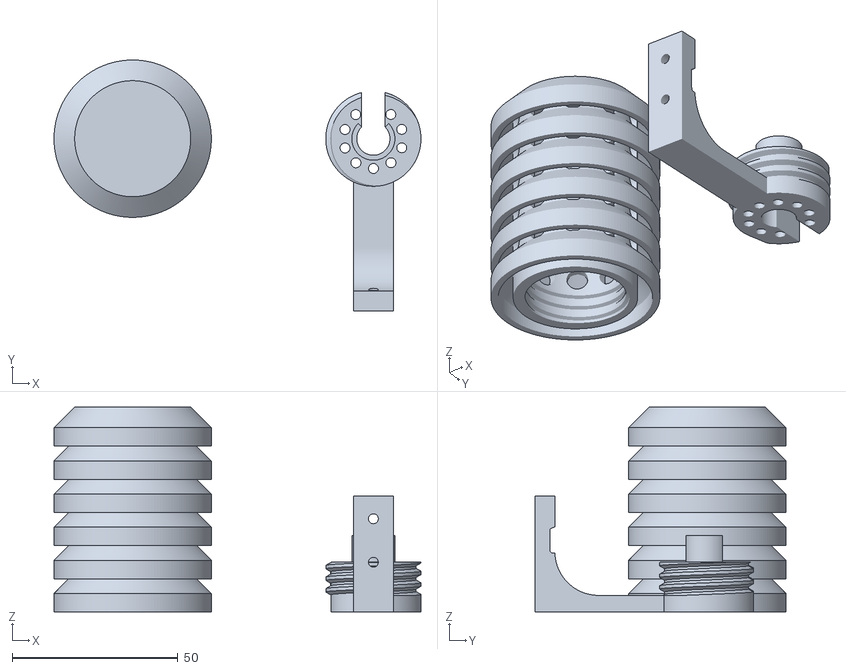
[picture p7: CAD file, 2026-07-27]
hardware/sensor_housings/sht40_stevenson/upstream/stevenson_combined.stl
110.7 x 75.7 x 61.8

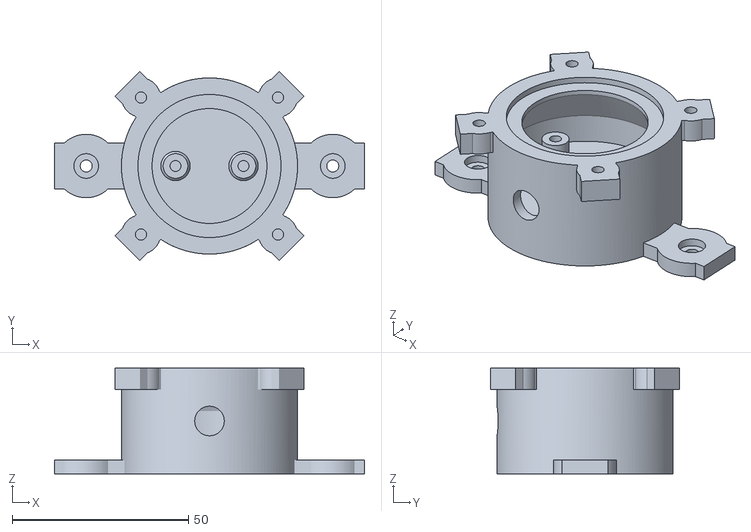
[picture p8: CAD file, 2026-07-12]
hardware/ultrasonic_anemometer/FreeCAD/stl/as7341_par_housing.stl
88.0 x 53.7 x 30.0

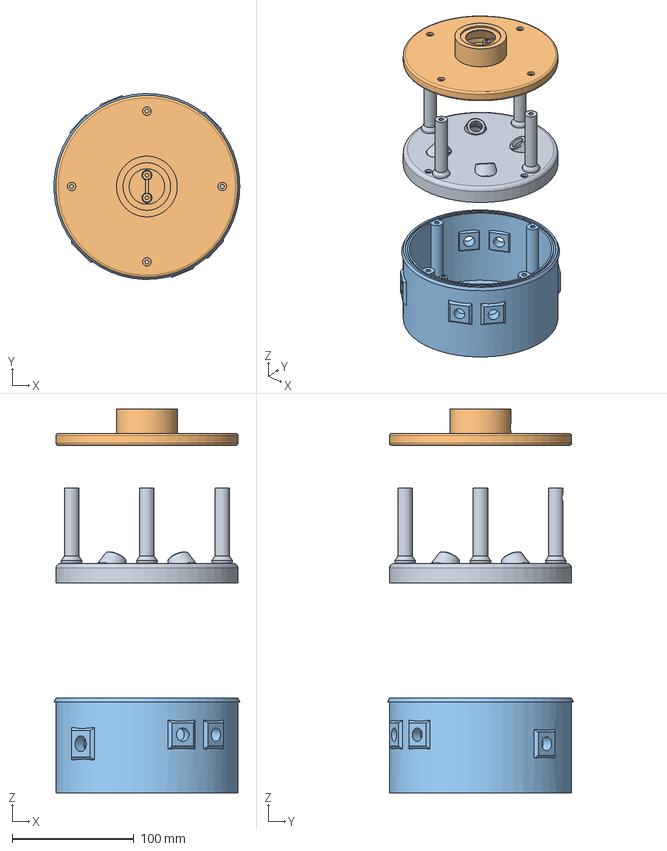
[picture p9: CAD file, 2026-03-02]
hardware/ultrasonic_anemometer/FreeCAD/Ultrasonic_Head_Improved.FCStd
152.9 x 152.9 x 316.0 mm
LowerBody
RoofPlate
BellyPan

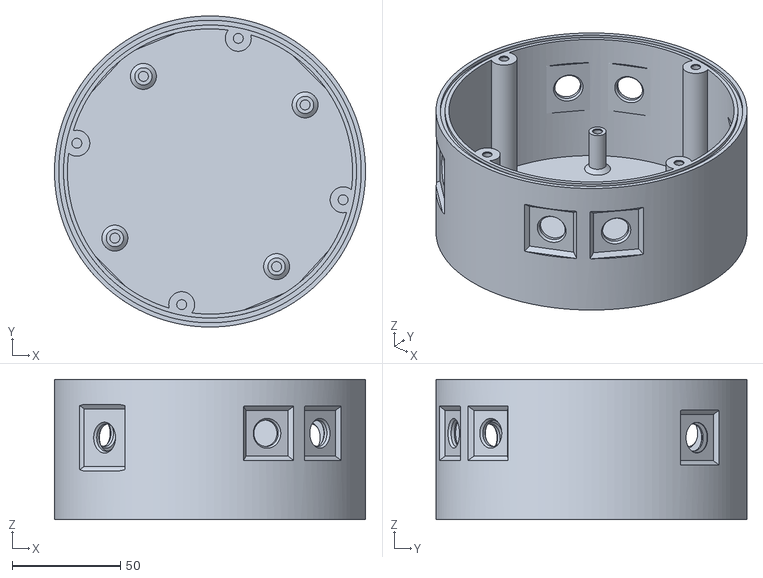
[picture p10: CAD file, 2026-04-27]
hardware/ultrasonic_anemometer/FreeCAD/V2/Version_2_belly.stl
144.0 x 144.0 x 65.0

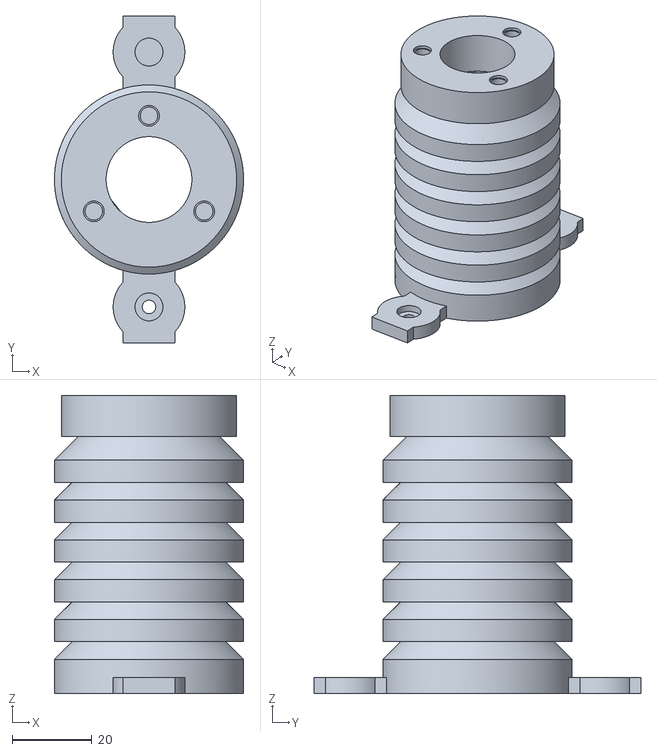
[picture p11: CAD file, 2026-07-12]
hardware/sensor_housings/sht40_stevenson/stl/sht40_stevenson_body_modified.stl
47.5 x 82.0 x 74.8

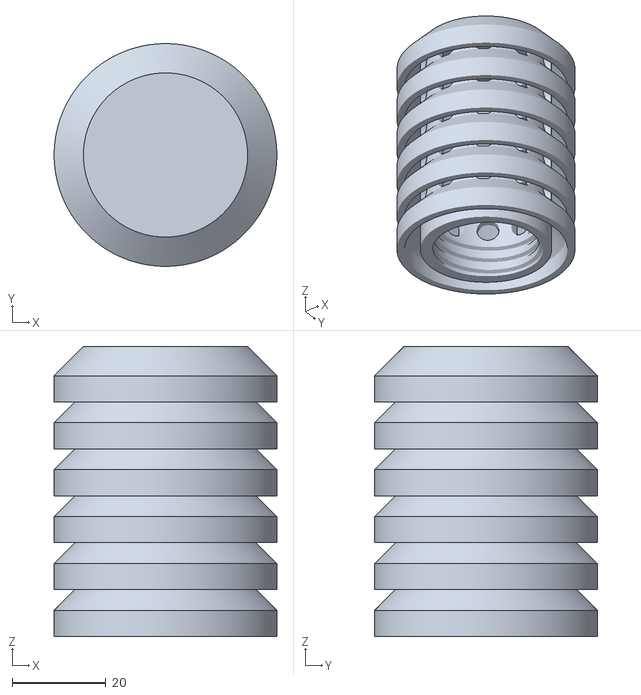
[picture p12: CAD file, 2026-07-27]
hardware/sensor_housings/sht40_stevenson/upstream/stevenson_cap.stl
47.5 x 47.5 x 61.8

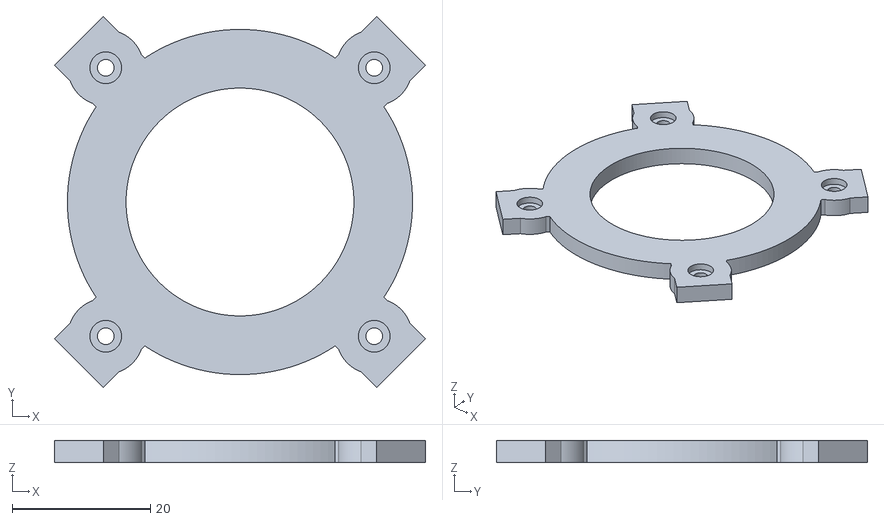
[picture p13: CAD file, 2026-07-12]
hardware/ultrasonic_anemometer/FreeCAD/stl/as7341_par_diffuser_retainer_ring.stl
53.7 x 53.7 x 3.20

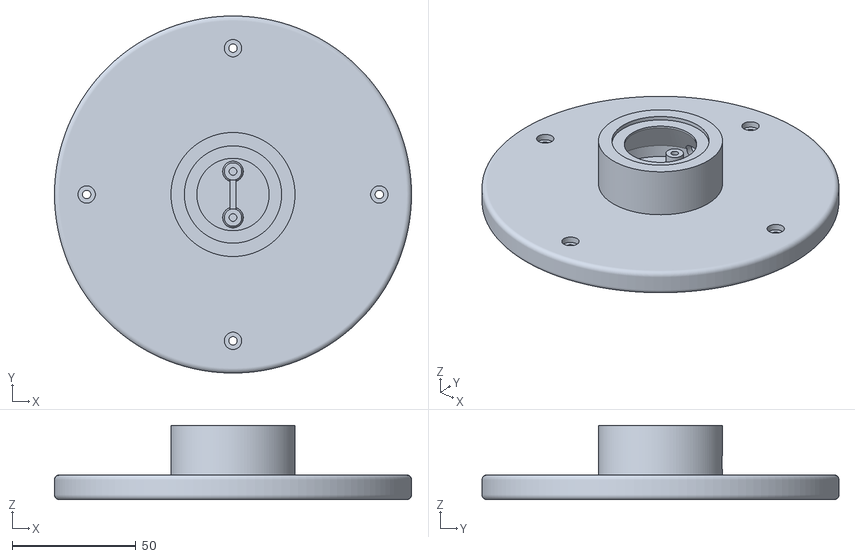
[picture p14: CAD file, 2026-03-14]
hardware/ultrasonic_anemometer/FreeCAD/V2/Version_2_roof.stl
144.0 x 144.0 x 30.0

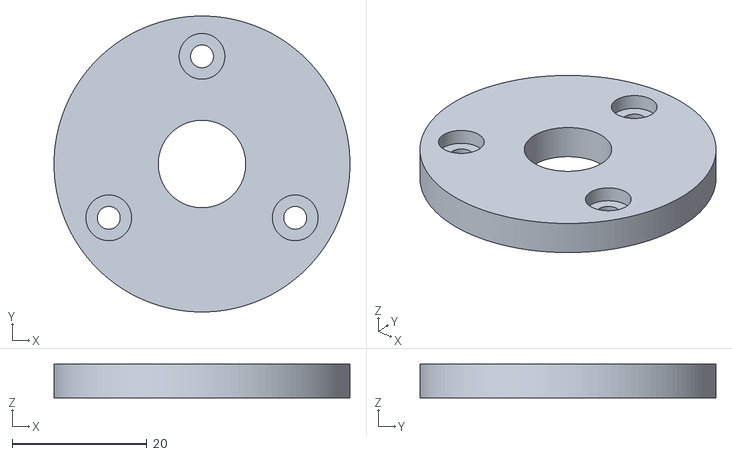
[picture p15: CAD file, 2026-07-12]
hardware/sensor_housings/sht40_stevenson/stl/sht40_pg7_retainer_flange.stl
44.0 x 44.0 x 5.00

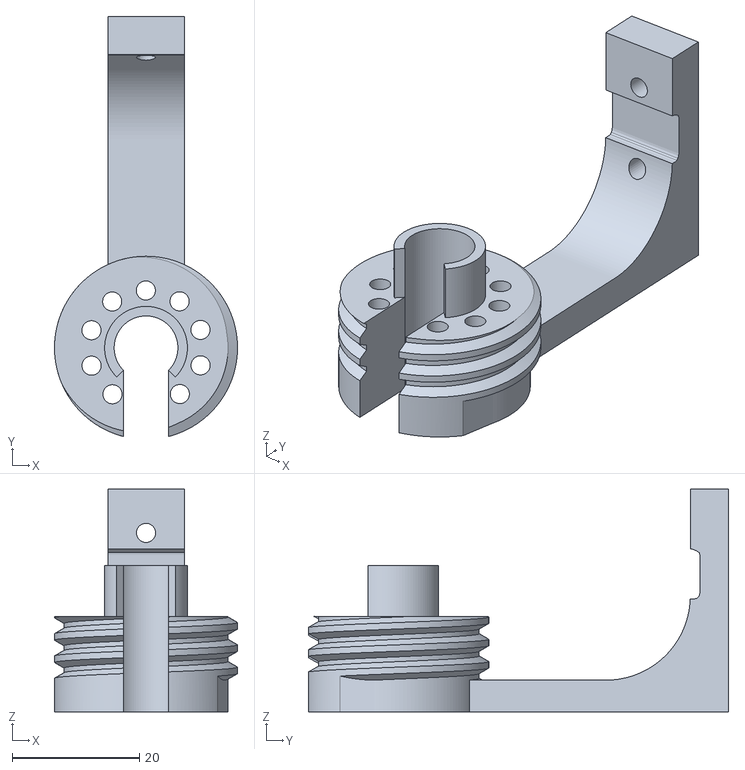
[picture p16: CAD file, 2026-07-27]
hardware/sensor_housings/sht40_stevenson/upstream/stevenson_base.stl
28.7 x 65.9 x 35.0

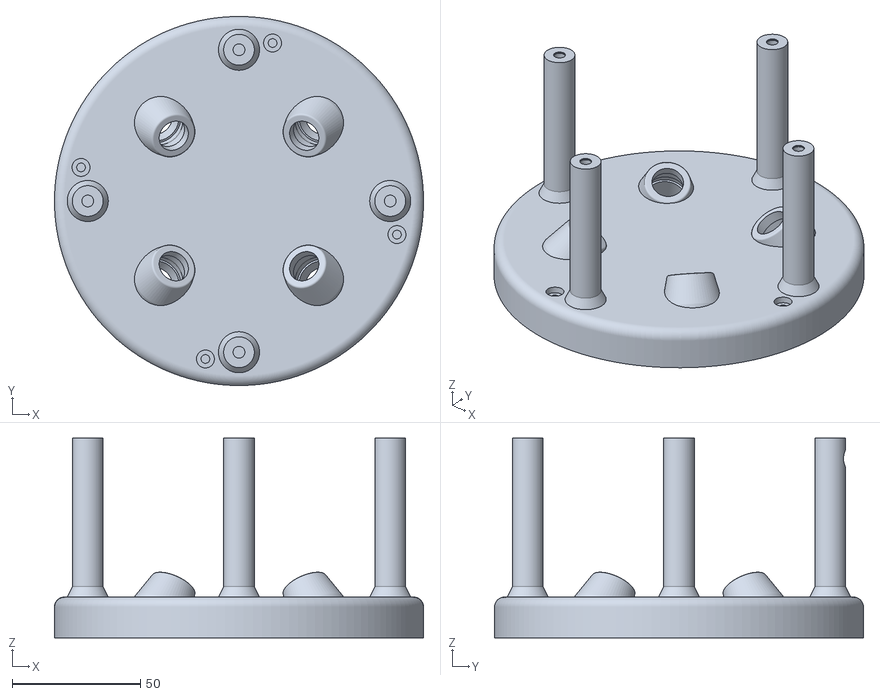
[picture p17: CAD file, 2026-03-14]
hardware/ultrasonic_anemometer/FreeCAD/V2/Version_2_plate.stl
144.0 x 144.0 x 78.0

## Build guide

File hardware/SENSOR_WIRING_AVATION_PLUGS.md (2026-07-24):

# Sensor Wiring — Aviation Plug Pinout

Reference pin assignments for sensors wired through aviation plugs.

## I²C Sensors (AS7341, SHT41, etc.)

All I²C sensors use the same 4-pin aviation plug mapping:

| Pin | Signal |
|-----|---|
| 1 | GND |
| 2 | SDA |
| 3 | SCL |
| 4 | PWR |

## Wind Sensor (Ultrasonic Anemometer)

2-pin aviation plug:

| Pin | Signal | Wire colour |
|-----|---|---|
| 1 | GND | Black |
| 4 | SIGNAL | Red |

## Soil Moisture Sensor

4-pin aviation plug:

| Pin | Signal | Wire colour |
|-----|---|---|
| 1 | GND | Black |
| 4 | PWR | Brown |
| 3 | Moisture | Yellow |
| 2 | Temp | Blue |

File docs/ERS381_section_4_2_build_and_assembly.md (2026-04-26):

## 4.2 Build and Assembly

This section describes how the node and mothership units were built for initial testing. The build process focused on reproducibility, low-cost replication, and a clear separation between sensing geometry and serviceable electronics.

### 4.2.1 PCB Design and Fabrication

Custom printed circuit boards (PCBs) were designed in EasyEDA for both node and mothership roles. The node board included the ESP32 microcontroller, power regulation, RTC and sensor interfaces, analog pathways, ultrasonic transmit/receive (TX/RX) circuitry, and connectors for modular expansion. The mothership board included ESP32-based communication, timekeeping, and logging interfaces for network coordination and data aggregation.

Boards were fabricated through JLCPCB using standard prototype workflows. Components were selected to be widely available and affordable, which reduced supply risk and supported repeat builds across multiple units.

To support independent replication, circuit schematics, PCB layout files, bill of materials (BOM), and fabrication outputs (for example, Gerber and drill files) were prepared as supplementary artefacts in the project repository.

Where specific manufacturer process settings (for example, copper weight, solder mask options, or panelisation choices) were not consistently recorded across all prototype iterations, they should be treated as implementation details, not protocol-critical requirements.

### 4.2.2 Electronics Assembly

Before first power-up, assembled boards were visually inspected for solder bridges, incomplete joints, and polarity-sensitive placement errors. Particular attention was given to diode orientation, regulator placement, continuity in the ultrasonic TX/RX path, and sensor connector orientation.

After connectors and sensor leads were installed, initial electrical checks were performed on a bench supply. These checks verified expected supply rails, basic boot behaviour, and serial console output from the microcontroller. Only boards that passed these checks were moved to enclosure integration.

Where V1 assembly rework was required (including polarity and footprint-related issues identified during early bring-up), corrected units were re-checked from first power and rail verification before further integration.

### 4.2.3 Housing Design and Fabrication

The enclosure was designed in FreeCAD and manufactured using fused deposition modelling (FDM) 3D printing. This approach supported rapid design iteration, low-cost reproduction, and fabrication without specialised tooling.

The housing architecture followed a head-roof-belly layout. The head contained the ultrasonic sensing geometry and transducer pod interfaces. The roof provided shielding and mounted the PAR/diffuser assembly through integrated standoffs and seating features. The belly enclosed the electronics and battery, with features for gasket sealing, internal cable management, and board mounting.

CAD source files and STL outputs were treated as reproducibility artefacts and were prepared as supplementary materials in the project repository.

Where print-process parameters (for example, filament type, nozzle size, and exact layer settings) differed between prototype runs, they were treated as tunable fabrication choices rather than fixed methodological requirements.

### 4.2.4 Mechanical Assembly

Mechanical assembly started by installing the node PCB and battery in the belly compartment, followed by seating ultrasonic transducers in the angled pod features of the head assembly. The PAR sensor was mounted in the roof-diffuser subassembly using dedicated mount geometry.

Internal wiring was routed through internal channels and standoff paths so cables stayed outside the primary ultrasonic measurement volume. The roof/head assembly was then coupled to the belly to complete the enclosure.

The architecture was assembled so electronics could be serviced without full disassembly of the wind sensing geometry.

Where exact fastener specifications and torque settings were not systematically logged for all prototypes, assembly was guided by fit integrity and repeatable seating rather than fixed torque targets.

### 4.2.5 External Sensors and Cable Routing

External sensor interfaces were implemented as modular expansion ports to support variable deployment payloads. Cable glands or connector interfaces were positioned on lower enclosure flat-pad regions to keep cable penetrations stable and separated from the ultrasonic sensing head.

External cable routing was managed to avoid intrusion into the acoustic measurement region and to reduce local flow disturbance near the ultrasonic path. In this workflow, sensor and cable placement were treated as part of measurement design, not only as mechanical assembly.

Where site-specific external sensor placement protocols were not fully standardised, deployment teams were advised to document probe position, cable path, and orientation at installation time for interpretation of microclimate gradients.

### 4.2.6 Sealing and Weather Resistance

Weather resistance was implemented through a sealed lower electronics compartment, a continuous silicone cord gasket seated in the enclosure groove, and controlled cable-entry points via glands/connectors.

Sealing quality was assessed during assembly and commissioning through fit checks and short-duration operation. Formal ingress testing to an IP-standard protocol was not performed in this phase, and no formal waterproof or dustproof rating is claimed.

Accordingly, enclosure performance should be interpreted as field-oriented protective sealing rather than certified environmental hardening.

### 4.2.7 Pre-Commissioning Checks

Before full network bring-up, each assembled unit underwent a pre-commissioning check sequence:

1. Visual inspection of assembly integrity, connector seating, and cable strain relief.
2. Verification of expected supply rails under controlled power input.
3. Confirmation of microcontroller boot behaviour and serial output.
4. Basic communication checks across core buses and wireless control pathways.

These checks established minimum functional readiness and provided the transition to the staged bring-up procedure described in Section 4.3.

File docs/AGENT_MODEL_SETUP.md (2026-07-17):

# Agent Model Setup — Ollama Routing

This repo's custom agent stack is declared in `.github/agents/`. The `model:` field in each agent's frontmatter is a **hint to the Copilot model picker**, not a binding route. To actually stop the stack from falling back to Claude/GPT from your GitHub business-plan entitlement, the routing must be done outside the agent files.

> Read this once before changing models. The goal is: all chat traffic goes through your Ollama account, nothing quietly slips through to a Copilot-hosted model.

---

## 1. What is in the repo right now

`.github/agents/*.agent.md` now declare a `model:` fallback chain pointing only at Ollama `:cloud` models, with `minimax-m3:cloud` as the final fallback:

| Agent | Primary | Fallback 1 | Fallback 2 |
|---|---|---|---|
| `orchestrator` | `kimi-k2.6:cloud` | `nemotron-3-super:cloud` | `minimax-m3:cloud` |
| `Planner` | `nemotron-3-super:cloud` | `kimi-k2.6:cloud` | `minimax-m3:cloud` |
| `Explore Repo` | `qwen3.5:cloud` | `minimax-m3:cloud` | — |
| `Implement Change` | `glm-5.1:cloud` | `qwen3.5:cloud` | `minimax-m3:cloud` |
| `Review Changes` | `gemma4:31b-cloud` | `nemotron-3-super:cloud` | `minimax-m3:cloud` |

The former Positron role files were consolidated on 2026-07-17 into `docs/archive/LEGACY_AGENT_WORKFLOW_2026-05-24.md`. They are not invoked by the active workflow; current agent definitions live under `.github/agents/`.

---

## 2. What the `model:` field actually does

VS Code Copilot resolves `model:` against the **Copilot picker** — the list of model IDs your GitHub Copilot account exposes. Models that are not in that picker are ignored and the picker default is used.

Your `ollama list` currently shows only `:cloud` models:

```
nemotron-3-super:cloud
qwen3.5:cloud
glm-5.1:cloud
kimi-k2.6:cloud
minimax-m3:cloud
gemma4:31b-cloud
```

These are not in the Copilot picker. So the `model:` line on its own will **not** keep you off Claude/GPT — Copilot will fall through to your business-plan default.

The three ways to actually route through Ollama are below. Pick one.

---

## 3. Option A — Ollama VS Code extension (simplest, recommended)

This is the cleanest path. The Ollama extension registers Ollama as a chat model provider, and you can pick Ollama models in the Copilot model picker just like Claude or GPT.

1. Install [Ollama for Windows](https://ollama.com/download/windows) and confirm `ollama --version` works in PowerShell.
2. Sign in to Ollama and confirm `ollama list` returns your `:cloud` models.
3. Install the **Ollama** VS Code extension (`ollama.ollama`, publisher `ollama`) from the marketplace. This repo recommends it in [`.vscode/extensions.json`](../.vscode/extensions.json) — VS Code will offer to install it on next launch if you haven't already.
4. In VS Code, open Settings and search for `Ollama`. Set the default model to one of your `:cloud` models (e.g. `minimax-m3:cloud`).
5. In the Copilot chat, the model picker should now list your Ollama models. Pick one.
6. The `model:` hints in `.github/agents/*.agent.md` are now first-choice in the picker; if Ollama is the picker default they will resolve to Ollama models.

Verification: open a new chat, type `/agents`, pick `orchestrator`, send a one-line task. In the response, the model label should show an Ollama model name, not "Claude Sonnet" or "GPT".

> Note: this repo's `.vscode/extensions.json` lists `saoudrizwan.claude-dev` (Cline) as an **unwanted** recommendation. Cline can talk to Ollama, but it has its own Anthropic-first default and is easy to leave routed to a paid hosted model. If you intentionally want Cline + Ollama, remove it from `unwantedRecommendations` and configure Cline's API provider separately — see [Option C-prime](#9-c-line--ollama-alternative) below.

---

## 4. Option B — Continue extension (full IDE-level control)

Continue is an open-source VS Code AI extension that talks to Ollama directly. It can replace Copilot Chat for most workflows and exposes Ollama models as first-class.

1. Install Ollama for Windows (same as above).
2. Install the **Continue** extension (`Continue.continue`).
3. Open the Continue config (`~/.continue/config.json` on Windows: `%USERPROFILE%\.continue\config.json`) and add models:

   ```json
   {
     "models": [
       { "title": "Ollama: kimi-k2.6", "provider": "ollama", "model": "kimi-k2.6:cloud" },
       { "title": "Ollama: minimax-m3", "provider": "ollama", "model": "minimax-m3:cloud" }
     ]
   }
   ```

4. Use Continue's chat panel instead of Copilot Chat for the agent workflow. Continue does not read `.github/agents/*.agent.md`, so treat the agent files as documentation of the intended roles, and replicate the persona discipline in Continue's `config.json` (system prompts per "agent").

This option does not give you VS Code's `runSubagent` against the custom-agent files, but it gives you the most predictable Ollama-only behaviour.

---

## 5. Option C — `copilot-ollama-proxy` (keeps Copilot Chat as the UI)

A small proxy that translates Copilot's OpenAI/Anthropic-format requests into Ollama's API. The model picker still shows Claude/GPT, but every call is silently forwarded to Ollama. This is the only option where the `model:` field in `.github/agents/*.agent.md` is meaningful as a routing hint.

1. Install Ollama for Windows.
2. Install the proxy. There are several implementations; pick one and follow its README:
   - `bernardx0/copilot-ollama-proxy` (Node, simple)
   - `ddPn08/copilot-ollama-proxy` (more options, multiple model mapping)
3. Configure the proxy to map Copilot model IDs to your Ollama `:cloud` models. Example mapping:

   | Copilot model ID | Ollama target |
   |---|---|
   | `claude-sonnet-4` | `kimi-k2.6:cloud` |
   | `claude-opus-4` | `nemotron-3-super:cloud` |
   | `gpt-5` | `glm-5.1:cloud` |
   | `gpt-5-mini` | `qwen3.5:cloud` |

4. In VS Code, point Copilot at the proxy by setting the API base in `settings.json`:

   ```json
   {
     "github.copilot.advanced": {
       "debug.overrideChatAdapterUrl": "http://localhost:11434"
     }
   }
   ```

   (Exact key depends on proxy — use whatever it documents.)
5. Restart VS Code. The `model:` chains in the agent files will now resolve against the proxy, and Claude/GPT will never be hit.

> The Copilot business-plan entitlement is still signed in, but if every call is intercepted at the proxy the upstream is never reached. If you want belt-and-braces, sign out of the Copilot business plan and rely on the proxy alone.

---

## 6. Local vs cloud Ollama models

The models in your `ollama list` are all `:cloud`. They are hosted by Ollama, billed through your Ollama account, and do **not** run on your GPU. The `model:` field in this repo is configured for them.

If you later want true local execution, pull local quantisations and add them to the chains:

```powershell
ollama pull llama3.1:8b
ollama pull qwen2.5-coder:14b
ollama pull deepseek-r1:8b
ollama pull nomic-embed-text
```

Then update the `model:` lines in `.github/agents/*.agent.md` so the local models come first in the fallback chain (e.g. `model: ["qwen2.5-coder:14b", "qwen3.5:cloud", "minimax-m3:cloud"]`).

---

## 7. Sanity check after setup

After picking Option A, B, or C, run this checklist:

1. Open a new Copilot/Continue chat.
2. Confirm the model picker shows an Ollama model, not Claude or GPT.
3. Run `/agents` and pick `orchestrator`. Send: "Summarise the active agent stack."
4. Confirm the response header shows the Ollama model you expect.
5. If a subagent call still resolves to a hosted model, the `model:` field is being ignored — that is a Copilot build limitation, not a config bug. Switch to Option B (Continue) for predictable behaviour.

---

## 8. If a model name in the repo is wrong

The model strings in `.github/agents/*.agent.md` must match what `ollama list` returns exactly. To swap a model:

1. Edit the `model:` line in the affected `.agent.md` file.
2. Update the table in section 1 of this doc to match.
3. If you are on Option C (proxy), update the proxy's mapping table.

Do not edit the archived legacy files — they are reference material and the `ARCHIVED` placeholder is intentional.

---

## 9. C-line + Ollama alternative

If you prefer to use **Cline** (`saoudrizwan.claude-dev`) as your primary agent loop instead of the Copilot Chat custom-agent stack, you can route Cline to your local Ollama. Cline does not read `.github/agents/*.agent.md`, so treat those as a design document and replicate the per-agent persona discipline inside Cline's config.

1. Confirm Ollama is running locally and `ollama list` shows your `:cloud` models.
2. In VS Code, open the Cline panel and click the settings gear.
3. Set:
   - **API Provider**: `OLLAMA`
   - **Base URL**: `http://localhost:11434`
   - **Model ID**: one of your `:cloud` models (e.g. `kimi-k2.6:cloud`)
4. Save. Cline now resolves every prompt against Ollama, not Anthropic.
5. Optionally remove `saoudrizwan.claude-dev` from `unwantedRecommendations` in `.vscode/extensions.json` if you want it explicitly recommended to other contributors.

Verification: in Cline, send a one-line task. The response header should show the Ollama model name. Cline does not surface in the Copilot Chat `/agents` picker, so the `orchestrator`/`Planner`/etc. agents are dormant on this path — they only run if a Cline prompt is structured to do so.

> Cline and Copilot Chat custom agents are independent. You can keep both installed: Cline for free-form agent work on Ollama, Copilot Chat for the `.github/agents/*.agent.md` workflow (which requires Option A, B, or the proxy to be Ollama-routed).

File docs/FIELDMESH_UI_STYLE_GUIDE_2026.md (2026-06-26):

# FieldMesh UI Style Guide — 2026

**Version:** 1.0  
**Product:** FieldMesh Dashboard  
**Audience:** Frontend developers, backend developers, UI designers, QA engineers, product owners, and repository agents  
**Primary users:** Ecologists, field technicians, researchers, environmental consultants, and project managers  

---

## 1. Purpose

FieldMesh is an environmental sensor monitoring platform designed for ecological fieldwork, research, deployment management, and long-term sensor monitoring.

This guide defines how the FieldMesh web application should look and behave as it evolves from a single-tenant monitoring dashboard into a multi-tenant SaaS platform.

The interface should feel:

- Modern and polished
- Scientifically credible
- Calm and ecological
- Data-rich without becoming visually crowded
- Reliable in both office and field conditions
- Accessible to researchers and non-technical users
- Consistent across desktop, tablet, and mobile

The goal is not to imitate a generic SaaS dashboard. FieldMesh should develop its own recognisable identity based on ecological monitoring, scientific clarity, and operational reliability.

---

## 2. Design Direction

### Scientific Calm

> Nature in the palette. Science in the structure. Operations in the interaction.

FieldMesh should feel ecological without looking decorative, rustic, or like a gardening website.

It should feel technical without becoming an industrial control panel.

Modern polish should come primarily from:

- Strong visual hierarchy
- Consistent spacing
- Clear typography
- Refined interaction feedback
- Responsive layouts
- Well-designed loading and error states
- Precise data visualisation
- Subtle depth and motion
- Clear status communication

Do not rely on glass effects, excessive gradients, animation, or bright colours to make the application appear modern.

---

## 3. Core Design Principles

### 3.1 Data First

Operational information must be visually stronger than decorative content.

The information hierarchy on most pages should be:

1. Current condition or primary result
2. Data freshness and reliability
3. Comparison or trend
4. Controls and filters
5. Supporting metadata
6. Explanatory content

A sensor value is incomplete without its:

- Unit
- Timestamp
- Source
- Data quality
- Device or node context

### 3.2 Progressive Disclosure

Show the information required for the current decision first.

Place advanced details such as the following behind secondary tabs, drawers, or expandable sections:

- Calibration data
- Firmware information
- Protocol values
- Raw payloads
- Device diagnostics
- Historical configuration
- API metadata

Do not hide important health, warning, or freshness information merely to make the interface look cleaner.

### 3.3 Consistent Semantics

The same visual treatment must always communicate the same meaning.

| Colour family | Meaning |
|---|---|
| Green | Working, connected, healthy, positive |
| Amber | Delayed, degraded, or requiring attention |
| Red | Failed, offline, destructive, or critical |
| Blue | Informational, selected, or active |
| Grey | Neutral, unavailable, unknown, or disabled |

Do not use green simply because FieldMesh is an ecological product.

### 3.4 Field Resilience

The interface must remain understandable when:

- The network connection is slow
- Some devices have not reported
- Sensor data is incomplete
- Data is stale
- A chart contains gaps
- A project has hundreds of nodes
- The user is outdoors in bright light
- The user is working on a tablet or phone
- A request fails halfway through
- Realtime updates are temporarily unavailable

### 3.5 Accessibility by Default

FieldMesh should target **WCAG 2.2 AA**.

Accessibility must be included in the component system rather than added after pages are complete.

---

## 4. Design Tokens

FieldMesh components must use semantic design tokens rather than direct colour names.

Preferred:

```tsx
<div className="bg-surface text-text-primary border-border">
```

Avoid:

```tsx
<div className="bg-green-50 text-slate-900 border-gray-200">
```

Semantic tokens allow the application to support:

- Light and dark themes
- Consistent status behaviour
- Future brand changes
- High-contrast adjustments
- Reusable component styling

---

## 5. Colour System

### 5.1 Light Theme

| Token | Value | Intended use |
|---|---:|---|
| `background` | `#F4F7F2` | Main application background |
| `surface` | `#FFFFFF` | Cards, tables, and panels |
| `surface-subtle` | `#EAF0E8` | Filter bars and grouped areas |
| `surface-raised` | `#FFFFFF` | Dialogs, popovers, and menus |
| `text-primary` | `#172019` | Main text |
| `text-secondary` | `#59645C` | Supporting text |
| `text-muted` | `#758079` | Low-priority labels |
| `border` | `#CDD7CF` | Dividers and card boundaries |
| `border-strong` | `#AEBBB1` | Stronger control boundaries |
| `primary` | `#176B3A` | Primary actions and selection |
| `primary-hover` | `#11562E` | Hover and pressed state |
| `primary-soft` | `#DCEFE2` | Selected rows and soft highlights |
| `info` | `#1D5FA7` | Information and links |
| `warning` | `#9A6700` | Delayed or degraded state |
| `danger` | `#B42318` | Failure and destructive actions |
| `unknown` | `#68736B` | Unknown or unavailable state |

### 5.2 Dark Theme

| Token | Value | Intended use |
|---|---:|---|
| `background` | `#0E1511` | Main application background |
| `surface` | `#151F19` | Cards and panels |
| `surface-subtle` | `#1A261E` | Grouped areas |
| `surface-raised` | `#1D2A22` | Popovers and dialogs |
| `text-primary` | `#F3F7F3` | Main text |
| `text-secondary` | `#A8B5AA` | Supporting text |
| `text-muted` | `#87958A` | Low-priority labels |
| `border` | `#314238` | Dividers and boundaries |
| `border-strong` | `#44594B` | Stronger boundaries |
| `primary` | `#75D092` | Primary actions |
| `primary-hover` | `#8FDEA7` | Hover and pressed state |
| `primary-soft` | `#183B26` | Selected and highlighted areas |
| `info` | `#72A7E3` | Information |
| `warning` | `#E1AD4C` | Warning |
| `danger` | `#F07B72` | Error and destructive action |
| `unknown` | `#9AA59D` | Unknown or unavailable state |

Use an off-black dark background rather than pure black.

Provide a persistent theme selector with:

- Light
- System
- Dark

### 5.3 Contrast Requirements

- Normal text: minimum contrast ratio of **4.5:1**
- Large text: minimum contrast ratio of **3:1**
- Essential icons: minimum contrast ratio of **3:1**
- Control boundaries: minimum contrast ratio of **3:1**
- Meaningful chart graphics: minimum contrast ratio of **3:1** where applicable

Do not communicate status through colour alone.

Add at least one additional cue:

- Text label
- Icon
- Shape
- Pattern
- Dash style
- Position
- Accessible description

---

## 6. Typography

Use a single primary font family for operational screens.

```css
font-family:
  InterVariable,
  Inter,
  ui-sans-serif,
  system-ui,
  -apple-system,
  BlinkMacSystemFont,
  "Segoe UI",
  sans-serif;
```

Use the system monospace stack for:

- MAC addresses
- Device IDs
- API values
- Coordinates
- Protocol fields
- Hex values
- Raw payload fragments
- Firmware versions

### 6.1 Type Scale

| Role | Size / line height | Weight |
|---|---:|---:|
| Page title | `28px / 36px` | 700 |
| Section title | `22px / 30px` | 650–700 |
| Card title | `16px / 24px` | 600 |
| Body | `16px / 24px` | 400 |
| Dense UI | `14px / 20px` | 400–500 |
| Caption | `12px / 18px` | 500 |
| KPI value | `28–36px / 1.1` | 650–700 |
| Button | `14px / 20px` | 600 |

Use tabular numerals for changing values:

```css
font-variant-numeric: tabular-nums;
```

Apply this to:

- KPI values
- Timestamps
- Sensor readings
- Tables
- Coordinates
- Battery percentages
- Counts

### 6.2 Scientific Names

Common names should use normal body text.

Scientific names should be italicised.

Example:

```text
Grasshopper warbler
Locustella naevia
```

---

## 7. Spacing System

Use a 4-pixel base spacing scale.

```text
4, 8, 12, 16, 20, 24, 32, 40, 48, 64
```

Recommended defaults:

| Context | Spacing |
|---|---:|
| Card padding | `20–24px` |
| Dense table cell vertical padding | `10–12px` |
| Form field gap | `16px` |
| Related control gap | `8–12px` |
| Section gap | `32px` |
| Page gutter on mobile | `16px` |
| Page gutter on tablet | `24px` |
| Page gutter on desktop | `32px` |

Avoid arbitrary values unless a component genuinely requires them.

---

## 8. Shape and Elevation

### 8.1 Corner Radius

| Component | Radius |
|---|---:|
| Controls | `8px` |
| Small panels | `10px` |
| Cards | `12px` |
| Large panels | `16px` |
| Modal and drawer | `16px` |
| Status pill | `999px` |

Do not make every component pill-shaped.

### 8.2 Elevation Levels

| Level | Use |
|---|---|
| Level 0 | Page background |
| Level 1 | Cards and panels |
| Level 2 | Menus, dropdowns, and popovers |
| Level 3 | Modals and blocking dialogs |

Most dashboard cards should use a border and a very soft shadow.

```css
box-shadow:
  0 1px 2px rgb(20 35 25 / 0.04),
  0 6px 18px rgb(20 35 25 / 0.05);
```

Do not use strong shadows on every element.

---

## 9. Application Layout

### 9.1 Desktop

- Persistent left navigation: `240–256px`
- Collapsed navigation rail: `68–72px`
- Top application bar: approximately `64px`
- Maximum operational content width: approximately `1600px`
- Use a 12-column layout for major page structures
- Allow charts and tables to use the full available width

### 9.2 Tablet

- Collapsible navigation rail
- Two-column dashboard layout where possible
- Filter controls may wrap onto a second row
- Charts should normally remain full width
- Interaction targets should remain at least `44–48px`

### 9.3 Mobile

Recommended primary bottom navigation:

1. Dashboard
2. Charts
3. Nodes
4. Config
5. More

Place the following under **More**:

- About
- Project management
- Account
- Theme settings
- Help
- Administrative pages

Do not shrink desktop tables until their content becomes unreadable.

Use either:

- Controlled horizontal scrolling with a sticky first column
- A deliberately designed mobile record layout
- Expandable rows for secondary fields

### 9.4 Responsive Components

Use:

- Viewport media queries for the application shell
- Container queries for reusable cards, chart headers, filter bars, and panels

Components should respond to the width available to them rather than relying entirely on the browser viewport.

---

## 10. Navigation

The main application shell should contain:

- FieldMesh logo and product name
- Active project selector
- Main navigation
- Global system or device health indicator
- User account menu
- Theme selector
- Help entry
- Connection state where relevant

### 10.1 Active Navigation State

The active item must use at least three visual cues:

- Background or side indicator
- Icon treatment
- Increased text weight

Do not use colour alone.

### 10.2 Project Switching

Project selection must be visually separate from page navigation.

The active project name must always remain visible.

When changing projects:

1. Immediately clear or replace project-scoped content
2. Display a loading state for the new project
3. Never display the previous project’s data under the new project name
4. Ensure every project-scoped query key includes `projectId`
5. Ensure every node-scoped query key includes both `projectId` and `nodeId`

---

## 11. Page Headers

Recommended structure:

```text
Dashboard
Project health and latest environmental readings

[Date range] [Refresh] [Last updated 2 min ago] [Live]
```

Page headers should normally include:

- Page title
- One-line description
- Primary page controls
- Data freshness
- Current scope
- Relevant status

Do not hide the last-updated time.

---

## 12. Dashboard

### 12.1 Information Hierarchy

Recommended dashboard order:

1. Fleet or project health
2. Current environmental overview
3. Recent trends
4. Deployment map or spatial context
5. Devices requiring attention
6. Alerts
7. Recent activity

The most important information should occupy the most visual space.

### 12.2 KPI Cards

Each KPI card should contain:

1. Short label
2. Main value
3. Unit
4. Comparison or trend
5. Data freshness
6. Optional sparkline
7. Optional warning or quality indicator

Example:

```text
AIR TEMPERATURE

18.4 °C
Down 1.2 °C over 24 hours

Last reading 4 minutes ago
```

Do not treat an upward trend as automatically positive.

Trend meaning depends on the metric.

Use neutral language unless a scientifically defined desirable direction exists.

### 12.3 Card Grouping

Do not turn every piece of information into a separate card.

Group closely related information when it supports comparison.

Examples:

- Temperature and humidity
- Soil moisture and soil temperature
- Node status and last report
- Storage usage and upload backlog

---

## 13. Status System

Use explicit operational states.

| State | Visual treatment |
|---|---|
| Live | Green dot and `Live` |
| Delayed | Amber clock and `Delayed` |
| Offline | Red disconnected icon and `Offline` |
| Never reported | Grey empty-circle icon and `Never reported` |
| Maintenance | Blue tool icon and `Maintenance` |
| Unknown | Grey question icon and `Unknown` |

Never display `Poor` merely because the current status is missing.

### 13.1 Dynamic Thresholds

Delayed and offline thresholds should be derived from the configured reporting interval.

Example:

```text
Expected every 30 minutes.
Last report received 1 hour 42 minutes ago.
```

### 13.2 Status Animation

Use pulsing animation only for genuinely active processes, such as:

- Upload in progress
- Live connection attempt
- Provisioning in progress

Do not make every live indicator pulse continuously.

---

## 14. Charts and Scientific Visualisation

Every chart should provide:

- Descriptive title
- Metric name
- Unit
- Date range
- Timezone
- Clearly labelled axes
- Visible missing-data gaps
- Data source or quality context
- Accessible textual summary or data table
- Export action where useful

### 14.1 Chart Styling

| Element | Guideline |
|---|---|
| Standard line | `2px` |
| Selected line | `3px` |
| Grid lines | Subtle and low contrast |
| Axis labels | `12–13px` |
| Tooltip | Exact timestamp, value, unit, and node |
| Crosshair | Subtle dashed line |
| Point markers | Hidden normally; visible on hover or focus |
| Legend | Interactive when series can be toggled |

Do not smooth or interpolate across missing sensor readings.

A break in a line should represent a real break in observation.

### 14.2 Multi-Series Palette

Use a dedicated chart palette instead of semantic status colours.

```text
Blue       #2F6BC1
Orange     #B77900
Green      #2E8B57
Purple     #6D4CC4
Red        #C4473A
Cyan       #1688A8
Olive      #688C2E
Magenta    #8F2D56
```

For spectral channels, use wavelength-aware colours where useful, but also provide:

- Direct labels
- Dash patterns
- Selectable emphasis
- Accessible legend controls

Do not rely on eight colours alone to distinguish eight spectral lines.

### 14.3 Recommended Chart Types

| User question | Preferred chart |
|---|---|
| How did a metric change over time? | Line chart |
| How do several nodes compare? | Multi-line chart with selection |
| What is the hourly or daily pattern? | Heat map or grouped line chart |
| How are values distributed? | Histogram or box plot |
| Are two variables related? | Scatter plot |
| How much bounded capacity remains? | Progress bar |
| What are the wind directions? | Wind rose or polar chart |
| Where are the devices? | Map plus accessible list |

Avoid pie and donut charts when users need precise comparison.

Use gauges only for genuinely bounded metrics such as:

- Battery percentage
- Storage capacity
- Upload completion

Do not use gauges for:

- Temperature
- Detection count
- Species richness
- Arbitrary sensor quality
- Unbounded measurements

---

## 15. Maps

The map must never be the only way to find or select a node.

Always provide an accompanying list or table containing:

- Node name
- Status
- Last report
- Sensor type
- Location
- Battery
- Alerts

### 15.1 Map Behaviour

- Cluster dense markers
- Preserve the viewport while filters change
- Synchronise map and list selection
- Use marker shape or icon as well as colour
- Provide large zoom controls
- Provide `Fit to project`
- Provide copy-coordinate action
- Display coordinate system and precision where relevant

### 15.2 Marker Popover

```text
North Meadow 004
Live · reported 3 minutes ago

Battery        82%
Temperature    17.8 °C
Soil moisture  34%

[Open node]
```

---

## 16. Tables and Node Lists

Tables are appropriate for ecological and technical comparison.

Do not replace useful desktop tables with oversized cards purely to appear modern.

Provide:

- Sticky header
- Sort indicators
- Search
- Filters
- Active-filter summary
- Reset-filters action
- Column visibility controls
- Pagination or virtualisation
- Comfortable and compact density modes
- Keyboard focus
- Stable column widths

Recommended columns:

```text
Node | Status | Last report | Battery | Location | Sensors | Alerts
```

On mobile, keep these fields visible:

- Node
- Status
- Last report

Move secondary information into an expandable row.

Use skeletons that closely match the final row dimensions.

---

## 17. Forms and Configuration

Labels should appear above controls.

Placeholder text must not replace a label.

Recommended field structure:

```text
Label
Optional supporting text
Input
Validation message
```

Error messages should explain:

- What happened
- Which value is invalid
- How to fix it

Avoid:

```text
Invalid value
```

Prefer:

```text
Wake interval must be between 1 and 1,440 minutes.
```

### 17.1 Configuration Changes

For configuration changes:

- Show current value
- Show proposed value
- Show affected devices
- Explain when the change becomes active
- Preserve unsaved values after recoverable errors
- Warn before leaving with unsaved changes
- Confirm destructive or fleet-wide changes

Use radio buttons for a short visible set of mutually exclusive options.

Use selects for longer option lists.

Prefer vertical radio groups.

---

## 18. Buttons and Controls

### 18.1 Action Hierarchy

Use no more than one visually dominant primary action in a local action area.

```text
Primary:      Save configuration
Secondary:    Cancel
Tertiary:     View details
Destructive:  Delete project
```

### 18.2 Button Sizes

| Context | Size |
|---|---:|
| Compact desktop visible height | `36px` |
| Compact desktop hit area | `44px` |
| Standard button | `40–44px` |
| Touch and mobile | `48px` |

Adopt an internal target size of at least `44 × 44px` where practical.

### 18.3 Icon-Only Buttons

Every icon-only button requires:

- Accessible name
- Tooltip
- Visible focus state
- Minimum hit area
- Familiar icon
- Clear disabled state

Use Lucide icons consistently at:

```text
16px, 18px, 20px, or 24px
```

Do not mix unrelated icon families.

---

## 19. Modals, Drawers, and Popovers

Use:

| Component | Use |
|---|---|
| Modal | Focused decision or destructive confirmation |
| Drawer | Inspecting or editing a node while preserving page context |
| Popover | Brief contextual information |
| Full page | Complex workflows such as project creation or provisioning |

Do not place a modal over another modal.

When a modal opens:

1. Move focus into the modal
2. Keep keyboard focus inside the modal
3. Support Escape unless closing would be unsafe
4. Return focus to the triggering control after closing

---

## 20. Loading, Empty, Stale, and Error States

Every data-driven component must support:

1. Initial loading
2. Background refresh
3. Empty result
4. No matching filter result
5. Stale data
6. Offline state
7. Network failure
8. Permission failure
9. Partial data
10. Successful content

Do not replace loaded content with a full skeleton during background refresh.

Keep existing content visible and show a subtle refresh indicator.

### 20.1 Empty State

```text
No nodes have reported yet

Register a mothership or upload the first FieldMesh data package
to begin monitoring this project.

[Register mothership]
```

### 20.2 Filtered Empty State

```text
No nodes match these filters

[Clear filters]
```

### 20.3 Error Clarity

Differentiate between:

- No data exists
- Data has not arrived yet
- The user does not have permission
- The request failed
- The device is offline
- The data is stale
- Only part of the data loaded

---

## 21. Motion and Interaction

Recommended durations:

| Interaction | Duration |
|---|---:|
| Hover and focus feedback | `100–140ms` |
| Buttons and toggles | `140–180ms` |
| Panel transitions | `180–240ms` |
| Modal and drawer | `220–280ms` |

Use ease-out when content enters.

Use ease-in when content leaves.

### 21.1 Appropriate Motion

Motion may:

- Explain spatial change
- Confirm an action
- Direct attention
- Preserve orientation
- Show progress

Motion must not:

- Delay access to data
- Continually animate live values
- Bounce panels
- Animate every chart after each refresh
- Add large parallax effects
- Distract from operational status

Support:

```css
@media (prefers-reduced-motion: reduce) {
  /* remove or simplify non-essential motion */
}
```

Use translucent or glass-like surfaces only sparingly, such as:

- Top application bar
- Map controls
- About-page storytelling

Do not use transparency behind dense tables or charts.

---

## 22. About Page

The About page may be more visually expressive than the operational pages.

It may use:

- Larger typography
- Ecological illustrations
- Soft gradients
- Animated data-flow diagrams
- Layered hardware illustrations
- Scroll-based storytelling
- PCB and protocol visualisation

Dashboard, Charts, Nodes, and Config should remain calmer and more utilitarian.

Heavy visualisations should be lazy-loaded.

Reduced-motion preferences must still be respected.

---

## 23. Performance Standards

Preserve the existing small frontend bundle as a product strength.

Recommended budgets:

| Metric | Target |
|---|---:|
| Initial JavaScript | `≤ 120 KB gzipped` |
| Individual lazy route | Preferably `≤ 80 KB gzipped` |
| Initial CSS | `≤ 35 KB gzipped` |
| Largest Contentful Paint | `≤ 2.5 seconds` |
| Interaction to Next Paint | `≤ 200ms` |
| Cumulative Layout Shift | `≤ 0.1` |

Continue to:

- Lazy-load chart-heavy routes
- Lazy-load About-page diagrams
- Reserve dimensions for charts and images
- Defer non-critical code
- Virtualise genuinely large tables
- Pause unnecessary polling while the page is hidden
- Refresh stale data when the page becomes visible
- Avoid unnecessary rerenders
- Keep realtime events compact
- Query historical data rather than streaming all raw history

---

## 24. Accessibility Definition of Done

Every UI change should verify:

- Keyboard access works
- Focus is visible
- Focus is not hidden behind sticky navigation
- Interactive targets are at least `44 × 44px` where practical
- Normal text contrast reaches `4.5:1`
- Essential UI graphics reach `3:1`
- Information is not communicated through colour alone
- Zoom to 200% does not remove functionality
- Mobile reflow does not require full-page two-dimensional scrolling
- Controls have accessible names
- Dialog focus is managed
- Charts have a textual alternative
- Tables use semantic headers
- Errors are associated with their fields
- Reduced-motion mode works
- Light and dark themes are tested
- Loading, empty, stale, partial, offline, and error states are present

Use established WAI-ARIA interaction patterns for:

- Tabs
- Dialogs
- Comboboxes
- Menus
- Tooltips
- Listboxes
- Trees
- Disclosure controls

Do not invent custom keyboard behaviour unnecessarily.

---

## 25. Tailwind Token Foundation

Example CSS variables:

```css
:root {
  --fm-background: 244 247 242;
  --fm-surface: 255 255 255;
  --fm-surface-subtle: 234 240 232;
  --fm-surface-raised: 255 255 255;

  --fm-text-primary: 23 32 25;
  --fm-text-secondary: 89 100 92;
  --fm-text-muted: 117 128 121;

  --fm-border: 205 215 207;
  --fm-border-strong: 174 187 177;

  --fm-primary: 23 107 58;
  --fm-primary-hover: 17 86 46;
  --fm-primary-soft: 220 239 226;

  --fm-info: 29 95 167;
  --fm-warning: 154 103 0;
  --fm-danger: 180 35 24;
  --fm-unknown: 104 115 107;
}

.dark {
  --fm-background: 14 21 17;
  --fm-surface: 21 31 25;
  --fm-surface-subtle: 26 38 30;
  --fm-surface-raised: 29 42 34;

  --fm-text-primary: 243 247 243;
  --fm-text-secondary: 168 181 170;
  --fm-text-muted: 135 149 138;

  --fm-border: 49 66 56;
  --fm-border-strong: 68 89 75;

  --fm-primary: 117 208 146;
  --fm-primary-hover: 143 222 167;
  --fm-primary-soft: 24 59 38;

  --fm-info: 114 167 227;
  --fm-warning: 225 173 76;
  --fm-danger: 240 123 114;
  --fm-unknown: 154 165 157;
}
```

Example Tailwind mapping:

```ts
export default {
  theme: {
    extend: {
      colors: {
        background: "rgb(var(--fm-background) / <alpha-value>)",
        surface: "rgb(var(--fm-surface) / <alpha-value>)",
        "surface-subtle": "rgb(var(--fm-surface-subtle) / <alpha-value>)",
        "surface-raised": "rgb(var(--fm-surface-raised) / <alpha-value>)",

        "text-primary": "rgb(var(--fm-text-primary) / <alpha-value>)",
        "text-secondary": "rgb(var(--fm-text-secondary) / <alpha-value>)",
        "text-muted": "rgb(var(--fm-text-muted) / <alpha-value>)",

        border: "rgb(var(--fm-border) / <alpha-value>)",
        "border-strong": "rgb(var(--fm-border-strong) / <alpha-value>)",

        primary: "rgb(var(--fm-primary) / <alpha-value>)",
        "primary-hover": "rgb(var(--fm-primary-hover) / <alpha-value>)",
        "primary-soft": "rgb(var(--fm-primary-soft) / <alpha-value>)",

        info: "rgb(var(--fm-info) / <alpha-value>)",
        warning: "rgb(var(--fm-warning) / <alpha-value>)",
        danger: "rgb(var(--fm-danger) / <alpha-value>)",
        unknown: "rgb(var(--fm-unknown) / <alpha-value>)",
      },
    },
  },
};
```

---

## 26. Component Requirements

### 26.1 Card

A standard card should support:

- Title
- Description
- Optional status
- Optional action area
- Content
- Loading state
- Error state
- Empty state
- Dark mode
- Responsive padding

### 26.2 Status Badge

A status badge should support:

- Icon
- Text label
- Semantic colour
- Accessible text
- Compact and standard sizes
- Tooltip where thresholds require explanation

### 26.3 Metric Card

A metric card should support:

- Label
- Value
- Unit
- Trend
- Comparison period
- Freshness
- Quality state
- Optional sparkline
- Optional click-through action

### 26.4 Data Table

A data table should support:

- Sorting
- Filtering
- Search
- Pagination or virtualisation
- Column selection
- Loading state
- Empty state
- Error state
- Keyboard navigation
- Accessible headers
- Responsive behaviour

### 26.5 Chart Panel

A chart panel should support:

- Title
- Description
- Unit
- Timezone
- Date range
- Series selector
- Legend
- Loading state
- Empty state
- Error state
- Accessible summary
- Export action
- Responsive toolbar

### 26.6 Form Field

A form field should support:

- Label
- Description
- Required state
- Input
- Validation
- Error message
- Disabled state
- Read-only state
- Help action

---

## 27. FieldMesh-Specific UX Rules

### 27.1 Data Freshness

Every current value should make it possible to determine:

- When it was recorded
- When it was received
- Which node produced it
- Whether it is stale
- Whether it passed validation

### 27.2 Device Health

Device health must distinguish:

- Connection state
- Battery state
- Sensor state
- Storage state
- Upload backlog
- Configuration state
- Firmware state

Do not combine all failures into one vague `Poor` status.

### 27.3 Missing Data

Do not treat missing data as zero.

Use:

- Em dash
- `No reading`
- `Not reported`
- `Unavailable`

depending on context.

### 27.4 Time and Timezones

Always display the active timezone in chart and export contexts.

For ambiguous timestamps, provide:

- Local project time
- UTC where technically relevant
- Full timestamp in tooltip or details

### 27.5 Units

Units must be consistent and visible.

Examples:

- `°C`
- `% RH`
- `% VWC`
- `m/s`
- `mm`
- `nm`
- `V`
- `dB`
- `µmol/m²/s`

Do not mix units within a chart without clear axis separation.

### 27.6 Coordinates

Coordinates should:

- Use consistent decimal precision
- Offer copy action
- Identify coordinate reference system where relevant
- Avoid implying false precision

---

## 28. Realtime Behaviour

Realtime updates should not create visual instability.

When new values arrive:

- Update the relevant value
- Preserve user selections
- Preserve scroll position
- Avoid rerendering the full page
- Avoid replaying full chart animations
- Avoid layout shift
- Show a subtle update acknowledgement where useful

Historical chart data should normally remain query-based.

Realtime should focus on:

- Latest device snapshot
- Node status
- Alerts
- Upload completion
- New activity
- Configuration acknowledgement

---

## 29. Content Style

FieldMesh text should be:

- Direct
- Calm
- Specific
- Non-alarmist
- Technically accurate
- Understandable to non-developers

Prefer:

```text
Node has not reported for 2 hours.
```

Avoid:

```text
Critical communication failure detected!
```

Prefer:

```text
Upload failed. Check the device connection and try again.
```

Avoid:

```text
Something went wrong.
```

Buttons should describe actions:

- Save configuration
- Register mothership
- Open node
- Retry upload
- Clear filters
- Export CSV

Avoid vague labels such as:

- Continue
- Submit
- Click here
- Do it
- OK

---

## 30. Things FieldMesh Should Avoid

- Green text and green charts everywhere
- Excessive glassmorphism
- Low-contrast grey text
- Tiny icon-only controls
- Pill-shaped styling on every control
- More than one dominant action per panel
- Gauges without meaningful bounds
- Charts without units
- Smoothed lines across missing data
- Status represented only by coloured dots
- Replacing useful tables with decorative cards
- Animating charts after every refresh
- Full-page spinners during background updates
- Hidden timestamps
- Showing `Poor` when the state is unknown
- Nested modals
- Destructive actions beside primary actions
- Layout shifts when live data arrives
- Permanent credentials inside QR codes
- Dense animation on operational screens
- Using placeholder text instead of labels
- Treating missing readings as zero
- Displaying old project data after project switching
- Using colour alone for spectral series
- Mixing multiple icon families
- Direct backend calls from arbitrary components
- One-off colours and spacing values inside feature code

---

## 31. Recommended Review Checklist

Before merging a new page or major component, verify:

### Visual

- [ ] Uses semantic tokens
- [ ] Matches FieldMesh typography
- [ ] Uses the spacing scale
- [ ] Uses consistent radii and elevation
- [ ] Works in light and dark themes
- [ ] Maintains clear hierarchy

### Responsive

- [ ] Works on desktop
- [ ] Works on tablet
- [ ] Works on mobile
- [ ] Does not create accidental page-level horizontal scrolling
- [ ] Keeps primary actions available

### Data

- [ ] Shows units
- [ ] Shows freshness
- [ ] Distinguishes stale, missing, and failed data
- [ ] Preserves gaps in time-series data
- [ ] Does not treat missing values as zero

### Interaction

- [ ] Keyboard accessible
- [ ] Focus state visible
- [ ] Touch targets large enough
- [ ] Loading state present
- [ ] Empty state present
- [ ] Error state present
- [ ] Offline or stale state considered
- [ ] Background refresh does not remove existing content

### Security and Project Scope

- [ ] Active project is visible
- [ ] Project-scoped queries include `projectId`
- [ ] Node-scoped queries include `projectId` and `nodeId`
- [ ] Previous-project data cannot flash after switching
- [ ] Permission failures are handled explicitly

### Performance

- [ ] Heavy code is lazy-loaded
- [ ] Charts do not rerender unnecessarily
- [ ] Layout dimensions are reserved
- [ ] No unnecessary dependency added
- [ ] Large tables use pagination or virtualisation where needed

---

## 32. Reference Standards

This guide is based on principles from the following standards and design systems:

- WCAG 2.2
- WAI-ARIA Authoring Practices Guide
- Apple Human Interface Guidelines
- Material Design 3
- Microsoft Fluent 2
- IBM Carbon Design System
- GOV.UK Design System
- MDN Web Docs
- web.dev Core Web Vitals
- Supabase frontend and realtime architecture guidance

Useful references:

- <https://www.w3.org/TR/WCAG22/>
- <https://www.w3.org/WAI/ARIA/apg/patterns/>
- <https://developer.apple.com/design/human-interface-guidelines/>
- <https://m3.material.io/>
- <https://fluent2.microsoft.design/>
- <https://carbondesignsystem.com/>
- <https://design-system.service.gov.uk/>
- <https://developer.mozilla.org/>
- <https://web.dev/articles/vitals>
- <https://supabase.com/docs/guides/realtime>

---

## 33. Summary

FieldMesh should use a **scientifically calm** design language.

The platform should combine:

- Ecological warmth
- Scientific precision
- Modern SaaS polish
- Operational reliability
- Accessible interaction
- Strong data visualisation
- Responsive field usability

The interface should not attempt to look modern through decoration alone.

It should feel modern because it is:

- Clear
- Fast
- Consistent
- Responsive
- Accessible
- Trustworthy
- Thoughtfully detailed

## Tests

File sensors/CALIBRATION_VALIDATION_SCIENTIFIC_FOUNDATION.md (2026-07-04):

# Sensor Calibration & Validation — Scientific Literature Review

**Purpose:** Evidence-based peer review notes on sensor calibration, accuracy, and field validation drawn from scientific literature. This is the foundation for your data logger's sensor performance claims.

---

## 1. General Calibration Framework

**Source:** [Sensor Calibration Overview (ScienceDirect Topics)](https://www.sciencedirect.com/topics/earth-and-planetary-sciences/sensor-calibration)

Sensor calibration is the systematic adjustment performed on a sensor to make its output as accurate and error-free as possible. The framework is divided into two categories:

| Phase | Timing | Purpose |
|---|---|---|
| **Pre-deployment calibration** | Before field deployment | Establish calibration model (offset, gain, temperature corrections) |
| **Post-deployment calibration** | After field use | Network recalibration strategies; address sensor drift & environmental changes |

### Common Calibration Models
- **Offset and Gain Calibration** — linear correction for zero-point and sensitivity drift
- **Temperature and Humidity Correction** — environmental compensation
- **Sensor Array Calibration** — multi-sensor consistency (cross-validation)

### Validation Methodology
Calibration validation involves:
1. Individual sensor calibration assessment
2. Robustness testing (repeated experiments, noise injection)
3. If poor performance, revisit sensor modeling and unconsidered environmental factors

---

## 2. Accuracy vs. Precision in Environmental Sensors

**Sources:**
- [EPA Precision and Accuracy Study](https://www.epa.gov/sites/default/files/2014-08/documents/precisionandaccuracy.pdf)
- [Challenges and Opportunities in Calibrating Low-Cost Environmental Sensors (PMC)](https://pmc.ncbi.nlm.nih.gov/articles/PMC11175279/)

### Definitions
- **Accuracy** — how close a measured value is to the true value (systematic error)
- **Precision** — how repeatable measurements are (random error, variance)

### Inter-comparison Testing
Field validation typically uses:
- **Co-location technique** — deploy your sensor alongside a reference-grade monitor in real environmental conditions
- **Correlation analysis** — assess drift vs. time and weather conditions
- **Seasonal variability** — test in multiple seasons to capture environmental extremes

### Low-Cost Sensor Performance
Research shows **open-source and low-cost sensors CAN match commercial accuracy** when properly calibrated:
- Open-source sensors: **3.08% mean accuracy** (electrical conductivity study)
- Commercial sensors (uncalibrated): **9.23% mean accuracy**
- **Insight:** Careful calibration matters more than sensor cost.

---

## 3. Soil Moisture Sensors — Field Calibration Requirements

**Sources:**
- [Calibration and Field Validation of Smart Soil Moisture Monitoring (Harvard ADS)](https://ui.adsabs.harvard.edu/abs/2023EGUGA..2511699Y/abstract)
- [Laboratory Calibration and Field Validation of Soil Water Content and Salinity Measurements Using the 5TE Sensor (PMC)](https://www.ncbi.nlm.nih.gov/pmc/articles/PMC6928628/)
- [Designing and Field Calibration of Low-Cost Microcontroller-Based Soil Moisture Sensors (Nature Scientific Reports)](https://www.nature.com/articles/s41598-024-81288-z)
- [Calibration of Low-Cost Capacitive Soil Moisture Sensors for Irrigation Management Applications (MDPI)](https://www.mdpi.com/1424-8220/25/2/343)

### Key Finding: Laboratory ≠ Field
Laboratory calibration curves have **limited real-world utility**. Field-specific calibration is critical because:
- Soil properties vary (texture, salinity, density) even within a deployment area
- Sensor-soil contact changes with environmental conditions
- Seasonal effects (freeze-thaw, compaction) alter sensor response

### Performance Gains from Field Calibration
| Approach | RMSE (m³/m³) | Accuracy |
|---|---|---|
| Laboratory calibration only | 0.06 | ±6% |
| Field calibration | 0.03 | ±3% |
| **Improvement** | **50% reduction** | — |

**Result:** Field-calibrated low-cost capacitive sensors match standard (expensive) TDR sensors.

### Capacitive Soil Moisture Sensors
- **Accuracy:** Lower than 5% error when properly calibrated ✅
- **Cost:** 10–50× cheaper than TDR alternatives
- **Challenge:** Environmental factors (temperature, salinity) require correction models

### Validation Protocol
1. Collect undisturbed soil samples from deployment site
2. Dry-down (gravimetric method) across soil water content range
3. Measure sensor output at each moisture level
4. Fit calibration curve (typically polynomial or piecewise linear)
5. Deploy with recalibration points throughout season
6. Compare to periodic gravimetric samples to track drift

---

## 4. Sensor Network Calibration Strategies

**Source:** [Framework for Simulation of Sensor Networks Aimed at Evaluating In Situ Calibration Algorithms (PMC)](https://pmc.ncbi.nlm.nih.gov/articles/PMC7472635/)

Multi-sensor calibration requires additional considerations:

### Sensor Drift Drivers
[Environmental Stressors That Cause Sensor Drift](https://www.clarity.io/blog/which-environmental-stressors-most-often-trigger-calibration-drift-and-necessitate-shorter-calibration-intervals):
- **Temperature** — most significant; non-linear effects
- **Humidity** — affects electrical properties
- **UV exposure** — degrades optical sensors
- **Chemical exposure** — contaminant absorption, corrosion
- **Physical stress** — vibration, thermal cycling fatigue

### In Situ Calibration Algorithms
Post-deployment recalibration strategies include:
- **Relative calibration** — reference against a peer node (if available)
- **Bayesian updating** — incorporate new measurements to refine calibration model
- **Outlier detection** — identify and exclude anomalous readings before recalibration

### Network Validation Approach
Use numerical simulation to test calibration strategies before field deployment:
1. Model environmental phenomena (e.g., soil moisture diffusion)
2. Model sensor metrological properties (drift, noise, lag)
3. Simulate different calibration strategies
4. Identify performance bottlenecks and optimization opportunities

---

## 5. Spectral / Optical Sensor Validation

**Source:** [Dynamic Validation of Calibration Accuracy and Structural Robustness of a Multi-Sensor Mobile Robot (PMC)](https://pmc.ncbi.nlm.nih.gov/articles/PMC11207938/)

For optical/spectral sensors (e.g., AS7341 PAR sensors):

### Photometric Calibration
- **Reference light source** — calibrated lamp (e.g., Ulbricht sphere) at known lux/spectra
- **Dark measurement** — capture dark current (0 lux, lid closed)
- **Gain validation** — test all gain settings (0.5× to 512×) to ensure linearity
- **Saturation curve** — measure output vs. increasing light intensity; identify saturation threshold

### Environmental Compensation
- **Temperature correction** — spectral response shifts with temperature
- **Angular response** — diffusers or apertures should be angle-independent
- **Temporal stability** — measure the same scene daily for trend analysis

### Peer Comparison (Inter-comparison)
Deploy alongside:
- Certified reference spectrophotometer (if budget allows)
- Another calibrated PAR meter (cosine-corrected, known accuracy)
- Open-source sensor with published calibration (e.g., OpenSensors.io)

---

## 6. Data Quality & Outlier Detection

**Common Outlier Removal Strategies** (from air quality and aerosol studies):

1. **Range checks** — discard values outside physically plausible limits
   - Example: soil moisture cannot exceed porosity; VWC in [0.0, 1.0]
2. **Rate-of-change limits** — reject abrupt jumps (e.g., >0.1 m³/m³ per minute)
3. **Cross-correlation** — flag one sensor if it deviates >2σ from peer nodes
4. **Temporal filtering** — apply 5–10 minute rolling median to smooth noise without losing real transients

---

## 7. Peer Review Checklist — Before Publishing Sensor Data

- [ ] **Calibration model documented** — linear? polynomial? piecewise?
- [ ] **Calibration uncertainty quantified** — RMSE or % error stated
- [ ] **Reference standard identified** — what was used for comparison?
- [ ] **Environmental factors addressed** — temperature, humidity, drift compensation models
- [ ] **Field validation completed** — not just lab; tested in target deployment conditions
- [ ] **Sensor-specific protocol** — soil sensors need soil-specific calibration; spectral need light reference
- [ ] **Multi-node consistency** — if multiple sensors, inter-comparison data provided
- [ ] **Drift monitoring plan** — how will you detect and correct drift over months of deployment?
- [ ] **Data filtering documented** — outlier removal, smoothing, averaging logic explained
- [ ] **Metadata captured** — sensor ID, firmware version, calibration date, reference used

---

## 8. Recommended Reading Order

For your peer review framework, read in this order:

1. **Start here:** [Challenges and Opportunities in Calibrating Low-Cost Environmental Sensors (PMC)](https://pmc.ncbi.nlm.nih.gov/articles/PMC11175279/) — concise overview of low-cost sensor challenges
2. **For soil moisture:** [Nature Scientific Reports article on field calibration](https://www.nature.com/articles/s41598-024-81288-z) — directly applicable to your soil probes
3. **For spectral sensors:** [Optical/multispectral sensor calibration standards](https://www.sciencedirect.com/topics/earth-and-planetary-sciences/sensor-calibration)
4. **For network validation:** [Framework paper on in situ calibration algorithms (PMC)](https://pmc.ncbi.nlm.nih.gov/articles/PMC7472635/) — if you plan multi-node comparison

---

## 9. Quick Reference: Calibration Timeline

| When | Action | Evidence |
|---|---|---|
| **Before field deployment** | Lab calibration against reference standards | Calibration curve + uncertainty |
| **Week 1 of deployment** | Record baseline measurements vs. manual samples | Initial drift assessment |
| **Month 1–3** | Monthly gravimetric/reference checks | Drift rate estimate |
| **Quarterly** | Re-calibrate if drift exceeds 5% | Updated calibration model |
| **End of deployment** | Final accuracy assessment + lessons learned | Post-campaign report |

---

## Document Status
- Last updated: 2026-07-04
- Next step: Create sensor-specific validation protocols (soil, spectral, wind) based on this foundation

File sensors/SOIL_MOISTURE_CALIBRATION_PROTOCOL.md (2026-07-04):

# Soil Moisture Sensor Calibration Protocol

**Target sensors:** ADS1115 + capacitive moisture & temperature probes (VWC + temp)  
**Scientific basis:** [Field Calibration Study (Nature)](https://www.nature.com/articles/s41598-024-81288-z), [5TE Validation (PMC)](https://www.ncbi.nlm.nih.gov/pmc/articles/PMC6928628/)

---

## Phase 1: Pre-Deployment Calibration (Lab)

### Equipment Needed
- Reference soil samples (3–5 varieties: clay, loam, sandy loam, sand)
- Oven (105°C capable)
- Scales (±0.1g precision)
- Your ADS1115 + sensor setup (at target mounting angle)
- Deionized water
- Temperature-controlled environment (±2°C)

### Procedure: Dry-down Calibration Curve

1. **Baseline (dry):** Oven-dry soil at 105°C for 24h. Record **zero-point ADC reading** for each sensor at each soil type.
   
2. **Moisture increments:** Add water in steps (e.g., 5%, 10%, 15%, ... 35% volumetric water content).
   - **Method:** Gravimetric calculation: `VWC = (mass_water / mass_soil) × (soil_density / water_density)`
   - For each step, equilibrate soil in container for 30 min, then record ADC output + temperature.
   
3. **Temperature sweep:** At each moisture level, measure ADC output at 15°C, 25°C, 35°C. Record T with each reading.

4. **Fit calibration model** (example for one soil type):
   ```
   VWC = a₀ + a₁×ADC + a₂×ADC² + a₃×T + a₄×ADC×T
   ```
   Use least-squares regression to find coefficients.

### Deliverable
- One calibration curve per soil type (plot ADC vs. VWC, residuals shown)
- Fit uncertainty (R², RMSE in m³/m³)
- Temperature correction coefficients

---

## Phase 2: Field Site Survey (Before Deployment)

### Soil Sample Collection
1. At deployment site, collect **3–5 undisturbed soil cores** from the top 10–20 cm (sensor depth).
2. For each core, measure:
   - **Texture** (% sand/silt/clay by sedimentation or triangle diagram)
   - **Bulk density** (gravimetric method on core: dry mass / core volume)
   - **Organic matter** (loss on ignition method, or estimate from color)

3. **Classify soil type** using USDA triangle. Cross-reference to your lab calibration samples.

### Objective
Determine which lab calibration curve best matches your deployment soil. If no close match, plan an **on-site calibration** (see Phase 3).

---

## Phase 3: On-Site Field Calibration

### Setup
Deploy sensor in natural soil at target location. Use a **reference method** to ground-truth sensor readings.

### Option A: Gravimetric Validation (Low-cost, manual)
**Every 2–3 weeks**, collect soil samples adjacent to sensors:
1. Extract soil core at sensor depth
2. Weigh wet core immediately (prevent evaporation)
3. Oven-dry, re-weigh
4. Calculate true VWC
5. Record your sensor ADC reading at time of sampling
6. Plot **sensor reading vs. true VWC** — should align with lab curve; if not, adjust coefficients

**Timeline:** Collect 8–10 paired samples over the deployment season (wet and dry periods).

### Option B: Dual-Sensor Cross-validation (Higher confidence)
If budget allows, co-deploy a **calibrated reference sensor** (e.g., 5TE, CS655) alongside your ADS1115.
- Record both outputs daily for 2 weeks
- Plot correlation scatter: (your sensor) vs. (reference)
- R² should be >0.95; if <0.90, recalibrate

### Option C: TDR Soil Moisture Probe (Gold standard)
Measure soil volumetric water content with a TDR probe at sensor location once per month. Highest accuracy but expensive.

---

## Phase 4: Data Processing & Drift Monitoring

### Real-time Outlier Rejection
1. **Range check:** Reject VWC outside [0.0, 1.0]
2. **Rate filter:** Reject changes >0.15 m³/m³ per 60-min interval (unless heavy rain)
3. **Cross-sensor check:** If operating multiple nodes, flag if one deviates >0.1 from peers for >3 hours

### Drift Detection
Every 30 days:
1. Plot VWC from all nodes over the last month
2. Look for gradual trends (gain drift) or step changes (calibration shift)
3. If any sensor drifts >5% from baseline, perform gravimetric validation or re-calibrate

### Temperature Compensation
Before reporting VWC:
```
VWC_corrected = VWC_raw + T_correction_factor × (T_measured - 25°C)
```
Ensure all reported data includes temperature at time of measurement.

---

## Phase 5: Publication/Peer Review

### Claims to Support

**Claim:** "Soil moisture measurements are accurate to ±X m³/m³"

**Supporting evidence:**
- ✅ Lab calibration curves (one per soil type, R² values shown)
- ✅ Field site soil characterization (texture, bulk density)
- ✅ Gravimetric validation data (N samples, correlation plot)
- ✅ Drift assessment (monthly readings over deployment period)
- ✅ Temperature correction applied? Quantified?

### Data Reporting Template

```
Soil Moisture Measurement Quality

Sensor: ADS1115 + [model soil probe]
Deployment site: [location], soil type = [loam/clay/etc.]
Calibration method: Lab curve (soil type matched) + field validation
Reference standard: Gravimetric sampling (N=10 over 3 months)

Accuracy:
  - Lab calibration RMSE: ±0.031 m³/m³
  - Field validation (vs. gravimetric): R²=0.93, RMSE=0.035 m³/m³
  - Operational accuracy: ±0.05 m³/m³ (at 95% confidence)

Drift monitoring:
  - Baseline (day 1): [ADC reading at known reference point]
  - 30-day drift: ±2%
  - 90-day drift: ±5%
  - Recalibration applied: [date]

Temperature compensation: Yes, T-dependent model fitted
Range: 10–40°C, correction factor = [value] per °C
```

---

## Troubleshooting

### Problem: Lab calibration doesn't match field data
**Cause:** Soil type mismatch or field soil compaction/structure differs.  
**Fix:** Collect undisturbed core from deployment site, repeat lab dry-down on that exact soil.

### Problem: Temperature effects are large (>10% VWC error)
**Cause:** Sensor dielectric response is T-dependent.  
**Fix:** Fit higher-order T correction (quadratic) or use soil-specific T coefficients from literature.

### Problem: Sensor drifts >10% over a month
**Cause:** Sensor aging, electrical drift in ADS1115, or salt accumulation in soil.  
**Fix:** Check reference gravimetric sample at same time. If reference is stable, re-calibrate ADC. If both drift, suspect soil salinity change.

### Problem: Two identical sensors in same soil read differently
**Cause:** Manufacturing variation, different soil contact, or cable capacitance.  
**Fix:** Swap sensor probes in soil; if readings swap, it's sensor variation. Apply **individual calibration** to each unit.

---

## References & Further Reading

- [Calibration and Field Validation of Soil Water Content and Salinity Measurements Using the 5TE Sensor](https://www.ncbi.nlm.nih.gov/pmc/articles/PMC6928628/)
- [Designing and Field Calibration of Low-Cost Microcontroller-Based Soil Moisture Sensors](https://www.nature.com/articles/s41598-024-81288-z)
- [Calibration of Low-Cost Capacitive Soil Moisture Sensors for Irrigation Management](https://www.mdpi.com/1424-8220/25/2/343)

---

## Compliance Checklist

Before publishing soil moisture data:

- [ ] Lab calibration curves generated (R² >0.90)
- [ ] Field soil type identified and matched to lab curve
- [ ] Gravimetric validation completed (≥8 paired samples)
- [ ] Drift monitored monthly; all drifts <5% over 90 days
- [ ] Temperature compensation model fitted and tested
- [ ] Outlier/rate-of-change filters documented
- [ ] Measurement uncertainty quantified (RMSE in m³/m³ or %)
- [ ] Metadata logged: sensor ID, firmware version, calibration date, reference used
- [ ] Quality flags assigned: [VALID], [DRIFT_WARNING], [UNVALIDATED]

---

**Document status:** 2026-07-04  
**Next step:** Spectral sensor calibration protocol (AS7341 PAR)

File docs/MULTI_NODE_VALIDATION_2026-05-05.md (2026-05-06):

# Multi-Node Validation Summary — 2026-05-05

This note summarises the sensor, firmware, and logging validation work completed on 5 May 2026. It is intended as a manuscript handoff document for downstream writing and synthesis.

---

## 1. Manuscript-Ready Summary

On 5 May 2026, the sensor-node firmware and mothership logging pipeline were validated first on a single fully instrumented node and then on a three-node deployment test. The validated node configuration comprised an SHT4x air temperature/relative humidity sensor on PCA9548A mux channel 0, an AS7341/AS734x-family spectral sensor on mux channel 1, a dual-probe soil moisture/temperature path via ADS1015, and a battery voltage input. Firmware integration was updated so that the node correctly selected mux channels before sensor access, emitted the eight expected spectral bands into the shared snapshot structure, and propagated these values through the mothership into the SD-card CSV logger.

Single-node testing showed that the end-to-end path from sensor readout to queued snapshot, sync-window flush, mothership reception, and SD-card logging was operational. Logged rows contained valid battery, air temperature, humidity, spectral, and soil values with the expected `sensor_present` mask (`0x0137`). Subsequent three-node testing demonstrated concurrent operation over repeated wake cycles and a shared sync flush. All three nodes produced valid battery, air temperature, humidity, and soil records, and the mothership successfully logged a multi-node backlog during the sync window without transport failure. One node initially showed missing spectral output during the fleet test; this was treated as a local wiring issue rather than a firmware or logging defect, and the spectral path was subsequently corrected in hardware. Overall, the tests support the conclusion that the node firmware, ESP-NOW transport, queueing behaviour, sync scheduling, and mothership CSV logging are functioning as intended for multi-node deployment.

---

## 2. Test Conditions and Scope

### 2.1 Firmware / hardware scope validated

- Node firmware environment: `esp32wroom`
- Mothership firmware environment: `esp32s3`
- Wake cadence during deployment test: 1 min
- Auto-derived sync cadence: 18 min
- Logged wide-format schema: battery, air, 8 spectral bands, wind placeholders, dual soil channels, AUX placeholders, `sensor_present`, `quality_flags`, and `seq_num`

### 2.2 Sensor configuration under test

- SHT4x air temperature / relative humidity on mux channel 0
- AS7341/AS734x-family spectral sensor on mux channel 1
- ADS1015 soil path on root I2C bus
- Soil probe wiring used in production firmware:
  - `A0 = soil1 temperature`
  - `A1 = soil1 moisture`
  - `A2 = soil2 moisture`
  - `A3 = soil2 temperature`

---

## 3. Key Findings

1. The single-node integrated deployment path functioned correctly after firmware alignment.
2. The mothership received queued snapshots and wrote them to SD-card CSV with correct timestamps and node metadata.
3. Three-node sync-window flushing worked without evidence of a system-level queue or receive-path collapse.
4. Two nodes produced complete sensor groups (`sensor_present = 0x0137`) throughout the fleet test.
5. One node initially produced `sensor_present = 0x0133`, indicating absent spectral bands only; this was treated as a node-local wiring problem rather than a transport or firmware limitation.
6. Soil temperature values were stable and plausible across the test period. Soil moisture values were operationally useful for bring-up, but still represent provisional scaling rather than final manuscript-grade calibration.

---

## 4. Outcome Table

| Test stage | Platform / nodes | Primary objective | Outcome | Interpretation |
|---|---|---|---|---|
| Single-node integrated deploy | 1 node (`ENV_945DC4`) | Verify sensor capture -> queue -> sync flush -> mothership CSV | PASS | End-to-end logging pipeline validated with complete sensor set present |
| Single-node CSV check | 1 node (`ENV_945DC4`) | Confirm wide-format CSV rows contain expected channels and timestamps | PASS | Battery, air, spectral, and soil values logged correctly; `sensor_present = 0x0137` |
| Three-node wake/sync run | 3 nodes (`ENV_94DF54`, `ENV_945DC4`, `ENV_94E38C`) | Verify concurrent wake cycles and shared sync-window backlog flush | PASS with one local hardware issue | Multi-node scheduling, queueing, transport, and logging validated |
| Spectral validation during fleet run | Node-local comparison across 3 nodes | Check that all nodes emit 8 spectral columns | PASS for 2/3 nodes; one local wiring issue | Missing spectral values on one node were attributable to wiring, not a software-path failure |

---

## 5. Data Produced Table

The table below condenses the representative CSV output from the 5 May 2026 tests.

| Node | MAC | FW ID | Representative period | `sensor_present` | Air temp (deg C) | RH (%) | Spectral status | Soil1 moisture* | Soil1 temp (deg C) | Soil2 moisture* | Soil2 temp (deg C) | Summary |
|---|---|---|---|---|---:|---:|---|---:|---:|---:|---:|---|
| NODE 1 | `D4:E9:F4:94:DF:54` | `ENV_94DF54` | 21:46-22:04 | `0x0133` | 19.32-19.95 | 62.75-65.51 | Spectral absent during fleet run (`NaN` in all 8 columns); later attributed to wiring error | 0.24-2.76 | 19.33-19.62 | 2.76-3.36 | 19.23-19.71 | Air and soil channels valid; spectral path initially missing due to local hardware wiring |
| NODE 2 | `D4:E9:F4:94:5D:C4` | `ENV_945DC4` | 21:46-22:04 | `0x0137` | 19.14-19.39 | 64.66-65.49 | 8 spectral bands present; low but nonzero counts under test lighting | 2.28-2.68 | 19.04-19.42 | 2.40-2.76 | 18.90-19.23 | Complete sensor set logged correctly through repeated wake/sync cycles |
| NODE 3 | `D4:E9:F4:94:E3:8C` | `ENV_94E38C` | 21:47-22:04 | `0x0137` | 19.45-19.91 | 62.58-64.93 | 8 spectral bands present; low but nonzero counts under test lighting | 0.12-0.24 | 18.99-19.42 | 0.08-0.20 | 18.94-19.23 | Complete sensor set logged correctly through repeated wake/sync cycles |

\* Soil moisture columns should currently be treated as provisional operational outputs from the TH-A path rather than final calibrated volumetric water content.

---

## 6. Representative CSV Interpretation

- `ms_datetime` / `ms_sync_unix` represent mothership logging time, i.e. when the backlog was received and written to SD.
- `node_datetime` / `node_unix` represent the actual sampling time on the node.
- Repeated rows sharing the same `ms_datetime` but differing `node_datetime` are expected during sync-window backlog flushes.
- `0x0137` indicates the presence of battery, air temperature, air humidity, spectral group, soil1 group, and soil2 group.
- `0x0133` indicates the same set except the spectral group, which matched the node-local wiring issue observed on one unit.

---

## 7. Recommended Manuscript Framing

The tests on 5 May 2026 support three main claims suitable for manuscript text:

1. The integrated node firmware was able to acquire, queue, and transmit multi-sensor observations spanning air, spectral, and soil channels.
2. The mothership successfully synchronised with multiple nodes and consolidated queued records into a structured SD-card CSV log.
3. A temporary loss of spectral output on one node was traced to a wiring fault rather than a software or communications limitation, and therefore does not alter the overall conclusion that the architecture supports multi-node environmental sensing.

---

## 8. Cautions for Manuscript Use

- Soil moisture values should not yet be presented as final calibrated volumetric water content without additional scaling / calibration work.
- Wind and AUX channels were not active in these tests and should be described as placeholders or not-yet-validated channels.
- The fleet test validates operational behaviour over repeated cycles, but it should still be described as a controlled deployment-style bench/short-run validation rather than a long-duration field campaign.

---

## 9. Suggested In-Text Citations and APA References

If the manuscript needs explicit citations for the PCB design and fabrication platforms, the following wording can be used.

### 9.1 Example in-text citation wording

- Parenthetical style: PCB schematics and layouts were prepared in EasyEDA (EasyEDA, n.d.), and prototype boards were fabricated using JLCPCB's rapid PCB manufacturing service (JLCPCB, n.d.).
- Narrative style: PCB schematics and layouts were prepared in EasyEDA (n.d.), and the prototype boards were fabricated by JLCPCB (n.d.).

### 9.2 Reference list entries (APA 7th style)

EasyEDA. (n.d.). *Easy-to-use & free PCB design software*. Retrieved May 6, 2026, from https://easyeda.com/

JLCPCB. (n.d.). *JLCPCB*. Retrieved May 6, 2026, from https://jlcpcb.com/

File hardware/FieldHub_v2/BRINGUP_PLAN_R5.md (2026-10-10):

# FieldHub v2 revision 5 bring-up plan

- **Plan date:** 2026-10-10
- **Hardware under test:** `revisions/2026-10-08-r5`
- **Initial batch:** five boards
- **Primary objective:** prove power integrity and every hardware interface before
  allowing unattended battery charging or field deployment.

This is a staged acceptance plan. A board advances only when the current stage
has a recorded pass. Stop at the first unexplained over-current, rail error,
over-temperature, unstable waveform, reset, or corrupted write. Do not work
around a failure by moving to a later subsystem.

## Revision-5 microSD design check

The revision-5 source project and fabrication test netlist agree with each
other and with the SHOU HAN `TF-CARD H1.8 SY` (`C7529391`) drawing.

| Socket contact | Card function | Revision-5 connection | Result |
|---|---|---|---|
| TF1.1 | DAT2 | 10 kOhm pull-up to `3V3_SYS`; no SPI data connection | Correct |
| TF1.2 | CD/DAT3 | `SD_CS` to ESP32 GPIO13 through R24, 22 Ohm; 10 kOhm pull-up | Correct |
| TF1.3 | CMD | `SD_MOSI` to ESP32 GPIO23 through R26, 22 Ohm; 10 kOhm pull-up | Correct |
| TF1.4 | VDD | `3V3_SYS`, with C130 100 nF and C131 10 uF local bypass | Correct |
| TF1.5 | CLK | `SD_SCK` to ESP32 GPIO18 through R27, 22 Ohm | Correct |
| TF1.6 | VSS | GND | Correct |
| TF1.7 | DAT0 | `SD_MISO` directly to ESP32 GPIO19; 10 kOhm pull-up | Correct |
| TF1.8 | DAT1 | 10 kOhm pull-up to `3V3_SYS`; no SPI data connection | Correct |
| TF1.CD | Mechanical card-detect switch | Not connected | Intentional limitation |
| TF1.10-13 | Socket shell/anchors | GND | Correct |

The previous board fault was GPIO23/MOSI connected to TF1.8/DAT1 instead of
TF1.3/CMD. Revision 5 routes GPIO23 to TF1.3 and leaves TF1.8 as a pull-up-only
unused SPI contact, so that specific fault is fixed.

The footprint also matches the connector drawing:

- signal pads are 0.70 x 1.60 mm on 1.10 mm pitch;
- the contact order is `CD, 8, 7, ... 1` when viewed from the component side;
- the two 1.00 mm locating holes are present as NPTH and are 8.00 mm apart; and
- the four shell anchors match the recommended land pattern.

This confirms the design files, not the quality of a future assembly. The
continuity checks and powered SD tests below remain mandatory.

Exact socket datasheet:
<https://datasheet.lcsc.com/datasheet/pdf/f91cb3ef17480eaaa64b684100a3fff4.pdf?productCode=C7529391>

## 1. Prepare before boards arrive

### Lock the build inputs

The repository's revision-5 directory currently contains the EasyEDA project
and Gerber ZIP only. It does not contain a revision-5 BOM, pick-and-place file,
assembly drawing, or schematic PDF. That is sufficient for a bare-PCB order,
but not an independently reproducible PCBA order.

Before assembly, export the BOM and pick-and-place data from the exact
revision-5 source, archive the assembler's final files, and verify the preview.
Do not silently combine revision-5 Gerbers with an older BOM/CPL. If the
October 8 BOM/CPL are intentionally reused, formally compare every reference,
value, footprint, side, coordinate, and rotation against revision 5 and record
the result. In particular, require TF1 to be `C7529391`, not a merely similar
socket with a different contact or anchor pattern.

### Equipment

- current-limited bench supply with current logging, initially set to 3.8 V;
- DMM with resistance, diode, continuity, current, and min/max modes;
- oscilloscope with x10 probes and short ground springs;
- electronic load and, for charger tests, a supply/load arrangement that can
  safely sink charge current;
- thermal camera or contact thermocouples;
- USB data cable and a Linux serial device such as `/dev/ttyUSB0`;
- one blank, known-good 8-32 GB FAT32 microSD card, then at least two different
  card makes/capacities for margin testing;
- a protected 1S test cell whose manufacturer permits 600 mA charging;
- panel simulator or current-limited 6 V-class source before using the real
  solar panel;
- LTE antenna and activated SIM; attach the antenna before enabling the modem;
- known-good FieldMesh node and known-good I2C/analogue sensor loads;
- ESD mat, eye protection, and a fire-safe area for charging work.

### Firmware readiness

The usable physical SD regression target is:

```sh
cd mothership/firmware/v2
PIO_BIN="${PIO_BIN:-$HOME/.platformio/penv/bin/pio}"
"$PIO_BIN" run -e mothership-v2-test-sd-logger
"$PIO_BIN" run -e mothership-v2-test-sd-logger -t upload --upload-port /dev/ttyUSB0
"$PIO_BIN" device monitor --port /dev/ttyUSB0 --baud 115200
```

The explicit `PIO_BIN` fallback is needed on the present development machine,
where PlatformIO is installed in its virtual environment but `pio` is not on
the shell `PATH`.

Do not use `mothership-v1-sd-card`: its configured source file is absent from
this repository. Several other older hardware bring-up environments have the
same problem. Before the boards arrive, port or create small, self-contained
tests for power hold/config latch, RTC/alarm, battery ADC, sensor rails/I2C/ADC,
ESP-NOW, and basic modem power. Do not make the full application the only
diagnostic tool.

The current SD code requests 40 MHz immediately. Add a diagnostic-only speed
sweep of 400 kHz, 4 MHz, 10 MHz, 20 MHz, and 40 MHz so signal-integrity margin
can be distinguished from a wiring fault. Production speed should be the
highest rate that passes all cards and temperature/load conditions with margin,
not automatically 40 MHz.

## 2. Batch and evidence control

Label the boards `HUB-R5-01` through `HUB-R5-05` before testing.

- Use `HUB-R5-01` for the complete engineering sequence, including fault,
  power-cut, maximum-load, and thermal tests.
- Repeat the full sequence on `HUB-R5-02` to distinguish a design result from
  a one-board result.
- Run the shortened production acceptance sequence on boards 03-05 only after
  boards 01 and 02 pass.
- Keep one log per board. Record supply voltage/current, rail readings,
  firmware commit, SD-card identity, instruments, ambient temperature, pass or
  fail, rework, and links to scope captures.
- Photograph both sides before power and after any rework.

Never silently reclassify a failure as a pass after rework. Record the original
failure, the change, and the complete repeated stage.

## 3. Stage A — assembly and mechanical inspection

Inspect at magnification before connecting USB, a battery, a panel, sensors,
SIM, or SD card.

- Compare every populated value and orientation with the assembly BOM and
  placement preview.
- Check pin 1 and polarity on U5, U21, U30, U33, U38, U45, U49, U50, U51,
  U52, U58, U59, U60-U62, all diodes, LEDs, MOSFETs, electrolytics, and the
  battery holder.
- Confirm the exact `C7529391` socket is fitted at TF1 and that all eight card
  contacts, the CD contact, and all shell anchors are soldered.
- Inspect USB-C, SIM, U.FL, JST, terminal block, switches, and manual/THT parts.
- Confirm all four 3.4 mm mounting holes are open NPTH holes with no visible
  copper annulus. Check screw-head and enclosure clearance before fitting metal
  hardware.
- Confirm the ESP32 antenna region and board-edge notch are free of solder,
  metal, wiring, battery, fasteners, and enclosure hardware.
- Confirm SJ4/SJ5 and their alternative zero-ohm options match the documented
  configuration; do not guess from the schematic.

**Pass gate:** no wrong/missing part, reversed polarity, solder bridge, lifted
pin, blocked hole, damaged connector, or unexplained assembly discrepancy.

## 4. Stage B — unpowered electrical checks

Remove the RTC coin cell, main cell, panel, USB, sensors, SIM, antenna, and SD
card.

### Rails

Measure resistance to GND on:

- `BATT1` / `RAW_BAT`;
- `VSYS1` / `VSYS`;
- `AON2` / `KEEP_ALIVE`;
- `3V4` / `3V3_SYS` (the test-point name says 3V4, but the net is 3.3 V);
- `5V` / `5V_SYS`;
- `4V` / `M_VBAT`;
- `1V8` / `M_1V8`;
- `3V3_SEN` and `5V_SEN` at their connector pins.

Capacitors can make an ohmmeter reading rise. The reject condition is a stable,
low-resistance short or a value materially different from the other untouched
boards, not an arbitrary single resistance threshold.

### SD continuity matrix

With no card inserted, verify:

- TF1.4 to `3V3_SYS`: near zero Ohm;
- TF1.6 and shell pads 10-13 to GND: near zero Ohm;
- ESP32 GPIO13 to TF1.2: approximately 22 Ohm;
- ESP32 GPIO23 to TF1.3: approximately 22 Ohm;
- ESP32 GPIO18 to TF1.5: approximately 22 Ohm;
- ESP32 GPIO19 to TF1.7: near zero Ohm;
- TF1.1, 2, 3, 7, and 8 to `3V3_SYS`: each has its intended 10 kOhm pull-up
  path (allow for parallel paths/in-circuit meter effects);
- GPIO23 is not connected to TF1.8; and
- adjacent signal pads are not shorted.

TF1.CD is deliberately not routed to the ESP32. Its mechanical switching can
be characterised at the socket, but production firmware cannot use it.

### Connector harnesses

Continuity-test every cable before connecting a sensor. Record the view used
(PCB mating face, cable mating face, or solder face). The PCB assignments are:

| Connector | Pin 1 | Pin 2 | Pin 3 | Pin 4 |
|---|---|---|---|---|
| CN17-CN20 | `3V3_SEN` | GND | SDAx | SCLx |
| CN15 | `5V_SEN` | GND | A1 | A0 |
| CN16 | `5V_SEN` | GND | A2 | A3 |

**Pass gate:** no short, all required point-to-point paths agree with the
netlist, and all harnesses have a signed continuity record.

## 5. Stage C — first current-limited power

Do this without an SD card, SIM, sensors, panel, or production battery.

1. Set the bench supply to 3.8 V and 100 mA and connect it with correct polarity
   at the battery input. Keep a finger or thermal camera on the board.
2. If the board reaches current limit, disconnect immediately. Locate the load
   before raising the limit.
3. Exercise the intended wake/config action. Once there is no smoke-test fault,
   raise the limit only as required for an ESP32 boot, initially no more than
   500 mA with modem and sensor rails disabled.
4. Record input current in off, boot, idle/config, Wi-Fi-active, and shutdown
   states.
5. Verify `KEEP_ALIVE`, `VSYS`, `3V3_SYS`, and `5V_SYS`. Expected active values
   are approximately 3.3 V and 4.99 V; investigate any sustained value outside
   3.20-3.40 V or 4.85-5.15 V.
6. Check startup overshoot and ripple at U50 output and `5V_SYS` with the scope.
7. Repeat using 3.2 V, 3.8 V, and 4.2 V input after nominal operation passes.
8. Apply reverse polarity only with a very low current limit. Confirm Q37
   prevents downstream power and that current stays at the leakage/background
   level established by the circuit, not a rising or heating load.

The earlier desktop review raised questions about the 5 V converter geometry.
Treat those as a measurement target, not as a diagnosed failure. Probe U21,
L4, D6, C3/C75/C76, and the feedback network under load. Decide from ripple,
ringing, temperature, regulation, and ADC-noise results.

**Pass gate:** no unexplained current limit, overheating, rail overshoot,
brownout/reset loop, or rail outside its acceptance band across 3.2-4.2 V.

## 6. Stage D — USB, programming, ESP32, and hard-power control

1. With the bench supply still current limited, connect USB and confirm CH340C
   enumeration and a stable serial port.
2. Check that USB does not back-feed the battery or solar connector to an unsafe
   voltage/current.
3. Flash a minimal serial build, reset repeatedly, then flash the production
   build.
4. Verify EN/BOOT behaviour and that programming does not depend on manually
   forcing an undocumented signal.
5. Verify config-button wake, `PWR_HOLD` assertion, config-clear operation, web
   shutdown, and a clean physical power cut after releasing hold.
6. Perform 25 wake/hold/shutdown cycles while logging input current and reset
   reasons.
7. Verify Wi-Fi AP creation, dashboard access, and reliable USB serial operation
   with at least two cables/host ports.

**Pass gate:** 25 clean cycles, repeatable flashing, no unexpected back-feed,
and no boot strap or latch state that leaves the unit unpredictably on or off.

## 7. Stage E — RTC, coin cell, and autonomous wake

1. Confirm U49 responds at I2C address `0x68` before installing the coin cell.
2. Install a known-good CR1220 with correct polarity; set UTC time and remove
   main power for at least ten minutes.
3. Restore main power and verify retained time and oscillator status.
4. Exercise Alarm 1 and Alarm 2 separately, then together. Confirm the `ALM2`
   / `INT_RTC` line asserts, clears, and re-arms without disturbing the other
   alarm.
5. Verify scheduled wake from fully off, config wake priority, service/USB wake,
   and shutdown only after the next required alarm is confirmed armed.
6. Run at least 25 autonomous off-wake-work-off cycles.

**Pass gate:** retained UTC time, correct wake classification, no stuck-low
interrupt, and 25 consecutive autonomous cycles.

## 8. Stage F — microSD hardware and archive path

Use a blank card for destructive and power-cut tests.

### Static power

1. With no card fitted, confirm TF1.4 is 3.20-3.40 V and TF1.6/shell are GND.
2. Insert the card with power off. Confirm the 3.3 V rail does not collapse or
   show an abnormal resistance/current change.
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

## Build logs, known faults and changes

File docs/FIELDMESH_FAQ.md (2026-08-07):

# fieldMesh — Frequently Asked Questions

**Date:** 2026-06-28
**Audience:** Ecologists, field practitioners, and anyone deploying or operating a fieldMesh network
**Companion docs:**
- `docs/FIRMWARE_FUNCTIONALITY_FOR_ECOLOGISTS.md` — full end-to-end workflow
- `docs/concept_overview.md` — system architecture
- `docs/FutureRoadMap.md` — roadmap
- `docs/FIELDMESH_USER_ONBOARDING_BRIEF.md` — multi-tenant onboarding plan

---

## Getting Started

### Q: What do I need in the field to run a fieldMesh network?
A mothership unit, one or more sensor nodes, and a phone or laptop with WiFi. No internet connection is required for local operation. The mothership creates its own WiFi network (e.g. `Logger001`) and serves a web dashboard at `http://192.168.4.1/`. Nodes communicate with the mothership over ESP-NOW on the same WiFi channel.

### Q: How do I connect to the mothership dashboard?
1. Power on the mothership.
2. On your phone or laptop, join the WiFi network named `Logger001` (password: `logger123`).
3. A captive portal should open automatically on most phones. On a laptop, open a browser and go to `http://192.168.4.1/`.

### Q: Do I need to set the time on the mothership?
Yes — at least once. The mothership's DS3231 RTC is the time reference for all scheduling and logging. On first boot, use the "Set time" panel on the home page (tap "Use browser time" for convenience). The RTC is coin-cell backed, so time survives power loss after that.

### Q: What if I forget the WiFi password?
The default is `logger123`. The SSID is `Logger` + the device ID (e.g. `Logger001`). If the device ID has been changed, it will be shown in the About / Advanced panel on the home page.

---

## Nodes

### Q: How do I add a new node?
1. Power on the node.
2. Press and hold the pair button on the node for ~3 seconds until the green light appears.
3. On the mothership dashboard, tap **Find New Nodes** (or open the Nodes page and use the "Add New node" panel).
4. The node appears in the list as "New" (unpaired). Tap it to assign an ID, name, and activate it.

### Q: What is the difference between "New", "Connected", and "Active"?
- **New (Unpaired):** The mothership has seen the node but has no association. It is not collecting data.
- **Connected (Paired):** The node is registered to this mothership but not yet actively sampling.
- **Active (Deployed):** The node is sampling on its configured interval, queuing data, and syncing with the mothership.

### Q: How long does a node's battery last?
That depends on the wake interval and battery capacity. A node wakes, reads sensors in 2–3 seconds, and powers down with the radio off. At a 5-minute interval, a typical 18650 LiPo lasts several weeks. The dashboard shows each node's last reported battery voltage (green ≥ 3.9 V, orange 3.5–3.9 V, red < 3.5 V).

### Q: What happens if a node misses a sync window?
Nothing is lost. The node retains its queued readings (up to 24 records) and tries again at the next sync slot. If the queue fills, the oldest record is dropped and flagged with quality flag `0x0001` so the gap is visible in the CSV.

### Q: Can I change a node's recording interval without redeploying?
Yes. The recording interval is a global setting (Settings page). When you change it, the mothership pushes the new interval to all connected and active nodes at their next sync. Per-node overrides are planned for future firmware.

### Q: How do I remove a node from service?
Open the node's detail page, choose "Remove node", and confirm. The mothership sends an UNPAIR command and clears the node's ID, name, and notes. You will need to re-pair it with the pair button if you want to add it back later.

---

## Data & Storage

### Q: Where is my data stored?
Locally on the mothership in `/datalog.csv` (LittleFS flash on V1/V2, SD card on older production hardware). You can download it directly from the dashboard via the **Export Data** button.

### Q: What format is the CSV in?
Wide format — one row per node per wake cycle, with all sensor channels in columns. Sensors not fitted on a given node appear as `NaN`. See `FIRMWARE_FUNCTIONALITY_FOR_ECOLOGISTS.md` §7 for the full column list.

### Q: What is the difference between `ms_datetime` and `node_unix`?
`ms_datetime` is when the mothership received and logged the record. `node_unix` is when the node actually measured the sample. The difference is the buffering delay (expected and correct). Use `node_unix` for ecological analysis of measurement timing.

### Q: What does quality flag `0x0001` mean?
The record was preceded by a queue overflow — a gap may exist in the data stream before this row. All other records have `0x0000` (clean).

### Q: How much data can the mothership hold?
V1/V2 motherships use LittleFS flash (typically ~1 MB usable). The dashboard shows storage used as a percentage. At a 5-minute interval with 5 sensors, a node produces ~150 bytes/row; 30 nodes at 5-min intervals generate ~1.3 MB/day. If flash fills, older data is not automatically purged — download and clear periodically for long deployments.

---

## Cloud Upload

### Q: How do I enable cloud upload?
Open **Settings → Connect to FieldMesh** (or go straight to `192.168.4.1/provision`). The connect flow has three steps: register the FieldHub in your project using the MAC it shows, scan or paste the connection code the dashboard gives you back, and save. Cloud upload is switched on automatically when the connection is saved.

> **Superseded:** an earlier build let you paste a `url|key` QR string on the Settings page to set the endpoint and key at once. That field and its parser have been **removed**. `url|key` carried an arbitrary endpoint straight into storage, bypassing the endpoint allow-list — a hub could be pointed at an unapproved host, and its connection key handed to whoever controlled it. The endpoint is now writable only by `/provision-apply`, from a validated `FM1` payload whose endpoint must be on the allow-list. Do not reintroduce a free-form endpoint field.

### Q: The FieldHub says "Re-provisioning required". What now?
It found a stored FieldMesh endpoint that is not an approved host, so it has disabled upload and erased its stored connection key. That key must be assumed exposed. In the dashboard, **revoke** the hub's connection key *first*, then generate a new one and run the connect flow again — generating a replacement does not disable the old key on its own. The warning stays on screen until a valid connection code has been saved.

### Q: What happens if the upload fails?
The mothership increments a retry counter and tries again at the next scheduled collection. Failed data stays in the upload queue — it is not lost. The dashboard shows a "Last upload failed" status indicator. Check antenna connection, signal strength, and API key validity.

### Q: Can I trigger an upload manually?
Yes, if "Allow manual upload" is enabled in advanced settings. A "Upload now" button appears on the Settings page. This powers on the LTE modem and transmits immediately — it takes 30–60 seconds and draws extra power.

### Q: Does cloud upload replace local storage?
No. LittleFS `/datalog.csv` remains the durable local record. Cloud upload is an additional egress path. If the modem or network is unavailable, data is still logged locally and queued for the next upload attempt.

---

## Scheduling

### Q: How is the sync interval determined?
The sync interval is auto-derived from the wake interval: `syncMin = wakeMin × 18`. This keeps the node queue at ~75% fill at sync time, with a 6-wake headroom before any overflow risk. You cannot set the sync interval directly — change the wake interval and sync follows.

| Wake interval | Auto sync interval |
|---|---|
| 1 min | 18 min |
| 5 min | 90 min |
| 10 min | 3 h |
| 30 min | 9 h |
| 60 min | 18 h |

### Q: Can I set a daily upload time instead of interval-based?
Yes. In Settings, switch the upload schedule to "Daily" and set a time (HH:MM). The mothership will upload once per day at that time. This is useful when LTE airtime cost is a concern.

### Q: What happens when I change the wake interval?
The mothership broadcasts the new interval to all connected and active nodes. Each node updates its NVS and re-arms its RTC alarm. The change takes effect at the node's next wake — no redeploy required.

---

## Power & Reliability

### Q: What happens if the mothership loses power?
All settings (wake interval, sync mode, node registry, API key) are stored in NVS and survive power loss. The DS3231 RTC is coin-cell backed, so time is preserved. On power restoration, the mothership resumes operation automatically. Nodes continue sampling independently — they don't need the mothership to be awake for each measurement.

### Q: What happens if a node loses power?
The node's state (paired/deployed, wake interval, mothership MAC) is in NVS and survives power loss. The DS3231 RTC is coin-cell backed. On power restoration, a deployed node reloads its state and resumes sampling automatically.

### Q: Do nodes need the mothership to be awake to measure?
No. Nodes wake on their own RTC alarm, read sensors, queue data, and power down — all without radio activity. The mothership is only needed during sync windows to receive the queued data.

---

## Future Plans

### Q: Will there be user accounts and a cloud dashboard?
Yes. The roadmap includes a multi-tenant platform on Supabase: users sign up, create projects, register motherships, and view isolated data in a real-time dashboard. See `FIELDMESH_USER_ONBOARDING_BRIEF.md`.

### Q: Will more sensor types be supported?
Yes. The roadmap targets an 8-port plug-and-play node where each port can be mapped to any sensor type (soil, PAR, wind, thermocouple, etc.) via a "Port Mapper" UI. Calibration coefficients will be manageable per-sensor and pushed wirelessly. See `FutureRoadMap.md` §2–4.

### Q: What about the ultrasonic anemometer?
An on-board ultrasonic anemometer is in development with PCB, mechanical, and OpenFOAM simulation assets. It will slot into the port-mapper system as a wind sensor backend. See `hardware/ultrasonic_anemometer/`.

### Q: Will OTA firmware updates be supported?
Yes — over ESP-NOW or WiFi AP, pushable to single nodes or the whole fleet. See `FutureRoadMap.md` §5.

### Q: Is there a native mobile app planned?
The roadmap includes a native app with real-time data, project management, and QR-based device provisioning. See `NATIVE_APP_FULL_CONCEPT_AND_SCHEMAS.md`.

---

## Troubleshooting

### Q: A node shows "n/a" for battery — why?
The node hasn't sent a battery reading yet. Battery voltage is reported in the first data packet after deploy. Wait for the next sync window or check that the node is powered and in range.

### Q: "Find New Nodes" didn't find my node — what do I check?
- Ensure the node is powered on and in pairing mode (green light after holding the pair button for 3 seconds).
- Ensure the node is within ESP-NOW range (typically ~100 m line-of-sight, less through vegetation/walls).
- Try pressing Find New Nodes again — the mothership sends 3 discovery bursts.

### Q: The dashboard clock is wrong — how do I fix it?
Open the "Set time" panel on the home page and tap "Use browser time", then "Set Time". This syncs the mothership RTC to your phone/laptop clock. All nodes will pick up the corrected time at their next sync.

### Q: My upload keeps failing — what should I check?
1. Verify the API key is correct (Settings → Cloud connection shows last 4 digits).
2. Check that the LTE antenna is connected and the SIM is active.
3. Check battery voltage — the modem won't power on below the minimum battery threshold (default 3700 mV).
4. Look at the retry count on the dashboard — if it's climbing, the modem is trying but failing to register on the network.

### Q: The captive portal doesn't open on my phone — what now?
Open a browser manually and navigate to `http://192.168.4.1/`. Some Android phones suppress captive portals for networks without internet — this is normal and doesn't affect functionality.

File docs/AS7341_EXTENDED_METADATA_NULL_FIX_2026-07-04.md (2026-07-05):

# AS7341 extended metadata null investigation

**Date:** 2026-07-04  
**Scope:** V2 node and mothership firmware only  
**Fields:** `spectral_clear`, `spectral_nir`, `spectral_gain`, `spectral_integration_ms`, `spectral_saturated`

## Result

The null conversion occurs when the mothership receives a V2 snapshot without sensor IDs 1109-1113:

```text
node V2 packet lacks IDs 1109-1113
  -> DecodedSnapshot.find(1109..1113) returns missing
  -> flash_logger writes nan in CSV columns 25..29
  -> json_payload converts each nan cell to JSON null
  -> Supabase faithfully stores explicit null values
```

The JSON mapping itself is correct. A production-function regression fixture now proves that finite ID/value pairs survive V2 decode, become a 30-column CSV row, and map to the five exact JSON field names.

## Confirmed node defect

The eight visible bands and the five extended values were not strictly bound to one exposure.

`read()` captured and cached the visible bands, but `getMetadata()` called `sampleIfNeeded()` again. The cache timestamp was recorded at the **start** of the potentially six-read auto-gain loop. By the time all registry sensors had been read and `buildReadingsArray()` requested metadata, more than 300 ms could have elapsed. This allowed `getMetadata()` to start a second AS7341 acquisition.

Consequences:

- if the second acquisition succeeded, Clear/NIR/gain/time could describe a different exposure from F1-F8;
- if it failed, `g_haveSample` became false, `md.valid` was false, IDs 1109-1113 were not appended, and all five values became `nan`/`null` downstream;
- the eight bands from the earlier successful exposure remained numeric, matching the observed database shape.

The fix:

- timestamps the cache when acquisition completes;
- makes `getMetadata()` read-only: it never starts an acquisition;
- makes `metadataAvailable()` require an existing successful sample;
- validates all four floating metadata values as finite;
- appends all five metadata entries atomically or none;
- logs the exact metadata and final snapshot capacity.

## Additional correctness fixes

### Auto-gain metadata

Previously, the final auto-gain attempt could change `g_gainIdx` and exit without acquiring at that new gain. Counts could therefore belong to the previous gain while metadata reported the next gain. Gain changes now occur only when another acquisition attempt remains, and failed gain writes invalidate the sample.

A failed `STATUS2` read now explicitly marks the exposure invalid and is logged. `spectral_saturated` remains numeric `0` or `1`.

### Capacity

The maximum registry has 20 readings. Capture adds at most one battery reading and five AS7341 metadata readings:

```text
20 + 1 + 5 = 26 <= MAX_READINGS_PER_SNAPSHOT (33)
```

A compile-time assertion enforces this. Runtime appending is all-or-nothing, so capacity pressure cannot create a misleading partial metadata set.

### Safe CSV schema migration

The previous `initFlash()` behavior deleted `/datalog.csv` whenever its header differed from the new header. That could silently erase unuploaded 25-column rows during a firmware upgrade.

The new policy is:

1. A current 30-column file is used normally.
2. A legacy 25-column file containing rows is preserved byte-for-byte.
3. New rows may append five trailing values; the first 25 positions remain unchanged.
4. Uploads are presented with the current 30-column superset header. Legacy rows simply lack the five trailing values; new rows contain them.
5. Once the cursor reaches EOF and all queued rows are drained, `purgeUploaded()` atomically replaces the empty file's legacy header with the 30-column header.
6. An unknown header is preserved and logging refuses to append an incompatible row instead of deleting data.

The flash logger and upload queue now share one header definition in `src/storage/csv_schema.h`.

## Boundary logging added

After flashing the new production builds, one successful exposure should emit:

```text
[FW] node build=<date time> protocol=2 spectral_metadata_ids=1109-1113
[PAR] ... CLR=<number> NIR=<number> GAIN=<number>x TINT=<number>ms SAT=<0|1> ...
[SENS-SPEC] appended ids=1109-1113 clear=<number> nir=<number> gain=<number> integration_ms=<number> saturated=<0|1> total=<n>/32
   [...] id=1109 value=<number>
   [...] id=1110 value=<number>
   [...] id=1111 value=<number>
   [...] id=1112 value=<number>
   [...] id=1113 value=<0|1>
```

The mothership should then emit:

```text
[FW] V2 snapshot decode; CSV schema=30; spectral metadata IDs=1109-1113
[SNAP-SPEC] ... extended=5/5 clear=<number> nir=<number> gain=<number> integration_ms=<number> saturated=<0|1>
[FLASH-SPEC] ... columns=30 extended_csv=number,number,number,number,number
[JSON-SPEC] csv_fields=30 spectral_clear=<number> spectral_nir=<number> spectral_gain=<number> spectral_integration_ms=<number> spectral_saturated=<0|1>
[JSON-SPEC-OBJECT] {..."spectral_clear":<number>,"spectral_nir":<number>,"spectral_gain":<number>,"spectral_integration_ms":<number>,"spectral_saturated":<0|1>}
```

If the first node log exists but `[SENS-SPEC] appended` does not, the new diagnostic states whether metadata was unavailable, non-finite, or lacked packet capacity. If the mothership reports `extended=0/5`, the values were already absent from the received node packet.

## Deployment identity

Repository HEAD at investigation start:

```text
5734e5d07cf1949f2640828d1ecb83aa53a67030
```

That commit introduced the extended metadata implementation. The prior commit cannot send IDs 1109-1113.

No USB ESP32 serial device was attached during the initial investigation, so the exact deployed images could not initially be identified. The mothership was subsequently attached and verified as described below; node verification is still pending.

New locally built production artifacts:

```text
node/firmware/v2/.pio/build/esp32wroom/firmware.bin
SHA-256 9A34761BFB7616E3697938EE01CD9739EF2646EAFE6D41CC8FA233056A6F1B12

mothership/firmware/v2/.pio/build/mothership-v1-main/firmware.bin
SHA-256 1D7F9E705F9713D1A1C5216DA678B405A4AD9A9B76158C2DB133C6875EF932FA
```

Build timestamps are also printed at boot. Capture those lines from each attached board before and after flashing. The mothership already sends its `firmwareBuild` in upload metadata; compare that value with its boot line.

### Mothership hardware follow-up, 2026-07-05

The mothership appeared as CH340 `COM4`. Its pre-flash boot identity was:

```text
Build: Jul  4 2026 13:53:43
```

It was flashed successfully with `mothership-v1-main`. The upload wrote the bootloader, partition table, OTA metadata, and application image; it did not write or erase the LittleFS/SPIFFS data partition at `0x310000`. Post-flash serial evidence was:

```text
Build: Jul  4 2026 19:30:12
[FW] V2 snapshot decode; CSV schema=30; spectral metadata IDs=1109-1113
```

This confirms the current 30-column decoder/logger/migration image is running on the mothership. A normal USB service wake does not receive a node snapshot, so the `[SNAP-SPEC]`, CSV, and JSON boundary evidence still requires the updated node and a data/sync wake.

### Node 1 hardware follow-up, 2026-07-05

Node 1 appeared as CH340 `COM4` with identity `ENV_6C0AA0`. Before flashing it detected the AS7341 and registered visible IDs 1101-1108, but its boot output did not contain the new `[FW] ... spectral_metadata_ids=1109-1113` marker. Its queue state before flashing was empty with `nextSeq=1174`.

The verified `esp32wroom` production image was uploaded successfully without erasing NVS. During the next scheduled data wake the node released `PWR_HOLD` and its CH340 disappeared, interrupting the host serial reader before the buffered exposure lines could be returned. A second physical wake is required to capture the post-flash build marker and inspect whether the queue advanced to sequence 1175. This is not yet counted as runtime proof of the five metadata values.

### Node 1 hardware follow-up, 2026-07-05

Node 1 appeared as CH340 `COM4` and identified itself as `ENV_6C0AA0`. Before flashing it detected the AS7341 and registered F1-F8, but its boot output did not contain the new marker:

```text
[FW] node build=<date time> protocol=2 spectral_metadata_ids=1109-1113
```

That proves the previously running application was not the final instrumented image. `esp32wroom` was flashed successfully twice at the operator's request. Esptool verified every written segment. The application upload did not erase the NVS partition, so node identity, deployment configuration, and its local queue were retained.

The board was disconnected before a post-flash data alarm completed, so a physical `[PAR]`/`[SENS-SPEC]` exposure and transfer to the mothership remain the next acceptance step.

## Verification performed

Successful compile targets:

```text
node/firmware/v2:        platformio run -e esp32wroom
mothership/firmware/v2:  platformio run -e mothership-v1-main
mothership/firmware/v2:  platformio run -e mothership-v2-test-spectral-pipeline
```

The focused regression firmware uses the production `decodeV2()`, CSV formatter, and `buildJsonUpload()` with:

```json
{
  "spectral_clear": 12000,
  "spectral_nir": 6800,
  "spectral_gain": 4,
  "spectral_integration_ms": 50.04,
  "spectral_saturated": 0
}
```

It asserts 13 decoded spectral readings, a 30-column row, correct values at positions 25-29, and five numeric JSON fields. The test image compiled successfully but was not executed because no ESP32 serial device was connected.

## Remaining hardware acceptance

The following require the physical node/mothership and cannot be fabricated from source inspection:

1. Record the pre-flash node `[FW]` build and mothership `Build:` line.
2. Flash both new production images.
3. Capture one exposure using the boundary logs above.
4. Download `/datalog.csv` from the mothership and verify the new row has 30 cells and numeric cells 25-29.
5. Trigger one JSON upload and retain `[JSON-SPEC-OBJECT]`.
6. Query the uploaded Supabase row by node ID and sequence number and confirm all five values are numeric.

Do not erase LittleFS to perform the upgrade. The migration is specifically designed to drain existing queued rows safely.

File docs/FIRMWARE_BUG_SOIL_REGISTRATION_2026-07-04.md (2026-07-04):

# Firmware Bug: Soil Sensor Registration Failure

**Affected firmware:** Node v2.0+ (soil_moist_temp backend)  
**Symptom:** Only SOIL1_VWC (sensor ID 2001) is registered; SOIL2_VWC, SOIL1_TEMP, SOIL2_TEMP disappear.  
**Impact:** 2 deployed nodes missing soil probe 2 data; snapshots have incomplete sensor list.  
**Root cause:** Sensor registration order doesn't match snapshot ID ordering; one of the registration slots fails silently.

---

## Evidence

**Node boot log (ENV_D13F98):**
```
[SOIL] ch0 raw=21232 mv=2654.0 → Tsoil1=23.70 °C
[SOIL] ch1 raw=1280 mv=160.0 → θv1=3.2000
[SOIL] ch2 raw=96 mv=12.0 → θv2=0.2400
[SOIL] ch3 raw=20864 mv=2608.0 → Tsoil2=22.59 °C
```
✅ All 4 channels read correctly by the ADS1115 hardware.

**Sensor registration:**
```
[SENS] soil_moist_temp backend reports 4 sensor(s)
[SENS] Slot 15 -> id=2001 label='SOIL1_VWC' type='SOIL_VWC' backend=2
```
❌ Only 1 slot registered, should be 4 (slots 15, 16, 17, 18).

**V2 snapshot:**
```
[16] id=2001  value=3.2000   ← only SOIL1_VWC appears
```
❌ IDs 2002, 2003, 2004 missing.

**Mothership fault detection:**
```
[SNAP] ENV_D13F98 sensor fault mask=0x0020 (expected=0x0037 present=0x0117)
```
✅ Mothership correctly flags SOIL2 (bit 0x20) as faulted.

---

## Root Cause

The soil backend's `label()` function returns indices in the wrong order for snapshot ID mapping:

**soil_moist_temp.cpp (lines 156–163):**
```c
const char* label(size_t index) {
  switch (index) {
    case 0: return "SOIL1_VWC";    // → resolves to sensor ID 2001
    case 1: return "SOIL2_VWC";    // → resolves to sensor ID 2003
    case 2: return "SOIL1_TEMP";   // → resolves to sensor ID 2002
    case 3: return "SOIL2_TEMP";   // → resolves to sensor ID 2004
  }
}
```

**Problem:** When `sensors.cpp` registers these 4 slots in the loop (lines 164–166), it calls:
```c
for (size_t i = 0; i < soilCount; ++i)
  commitSensorSlot(SENSOR_BACKEND_SOIL, i, label(i), type(i));
```

The registration loop succeeds for **index 0** (SOIL1_VWC, ID 2001), but the next 3 iterations don't produce logged `[SENS] Slot` lines. Either:
1. They're being masked/gated silently (no "[SENS] gated" message), or
2. One fails and subsequent iterations rely on state that's broken

**Secondary issue:** The V1 snapshot decode (flash_logger.cpp) can only handle the 8 bands + 4 soil values. Soil indices must map directly to the struct fields `soil1Vwc`, `soil1Temp`, `soil2Vwc`, `soil2Temp` in order. The current label order (VWC1, VWC2, TEMP1, TEMP2) breaks that.

**Tertiary issue:** The V2 snapshot stores (sensorId, value) pairs. The order doesn't matter for V2 — only the IDs. But if `commitSensorSlot()` silently fails on some indices, those IDs never get into the registry, and the backend won't read them at snapshot time.

---

## Fix

### Reorder the soil backend's label/type to match sensor ID order

**soil_moist_temp.cpp — fix the `label()` function:**

```c
const char* label(size_t index) {
  switch (index) {
    case 0: return "SOIL1_VWC";    // id 2001
    case 1: return "SOIL1_TEMP";   // id 2002
    case 2: return "SOIL2_VWC";    // id 2003
    case 3: return "SOIL2_TEMP";   // id 2004
  }
}

const char* type(size_t index) {
  switch (index) {
    case 0:
    case 2:
      return "SOIL_VWC";
    case 1:
    case 3:
      return "SOIL_TEMP";
  }
}
```

And update the `read()` function to match:

```c
bool read(size_t index, float &outValue) {
  if (index >= count()) return false;

  sampleAdsIfNeeded();
  if (!haveSample) return false;

  switch (index) {
    case 0: outValue = lastThetaV1; break;  // SOIL1_VWC
    case 1: outValue = lastTemp1C;  break;  // SOIL1_TEMP
    case 2: outValue = lastThetaV2; break;  // SOIL2_VWC
    case 3: outValue = lastTemp2C;  break;  // SOIL2_TEMP
    default: return false;
  }
  return true;
}
```

**Why this works:**
- Labels and types now reflect the **sensor ID order** (2001, 2002, 2003, 2004).
- `resolveSensorId()` in sensors.cpp will successfully map each to its ID without collision.
- All 4 slots get registered (no silent failures due to duplicate IDs or ordering issues).
- V2 snapshots include all 4 IDs in any order (doesn't matter).
- V1 snapshots (legacy) unpack in the correct order (soil1 data, then soil2 data).

### Bonus: Fix the moisture calibration bug

**sensors_soil_ads_calib.cpp:** The θv1 value logs as 3.2, which is outside valid range (0–0.6 m³/m³). This suggests either:
1. The calibration coefficients SOIL1_A0/SOIL1_B0/SOIL1_C0 are wrong, or
2. The raw voltage isn't being scaled before applying the calibration

Check the polynomial `theta_v_from_mv()` — it should take mV and return VWC. If it's receiving unconverted or double-converted input, it will produce garbage.

---

## Test Plan

After applying the fix:

1. Flash all affected nodes.
2. Boot a node and verify the sensor log:
   ```
   [SENS] soil_moist_temp backend reports 4 sensor(s)
   [SENS] Slot 15 -> id=2001 label='SOIL1_VWC' type='SOIL_VWC' backend=2
   [SENS] Slot 16 -> id=2002 label='SOIL1_TEMP' type='SOIL_TEMP' backend=2
   [SENS] Slot 17 -> id=2003 label='SOIL2_VWC' type='SOIL_VWC' backend=2
   [SENS] Slot 18 -> id=2004 label='SOIL2_TEMP' type='SOIL_TEMP' backend=2
   ```
3. Run a sync cycle and check the mothership:
   ```
   [SNAP] RX=... nodeId=ENV_D13F98 seq=... present=0x0137 proto=2 ...
   ```
   ✅ `present=0x0137` includes bits for SOIL1 (0x10) + SOIL2 (0x20) + SPECTRAL (0x04) + AIR (0x03) + BAT (0x100).
4. Verify the V2 snapshot body includes sensor IDs {2001, 2002, 2003, 2004}.
5. Check the mothership CSV — columns spectral_integration_ms (soil1Temp), soil1Vwc, soil2Vwc, soil2Temp should all be populated, no faults.

---

## Why This Happened

Soil sensor firmware was written with the ADS1115 hardware order in mind (ch0=T1, ch1=VWC1, ch2=VWC2, ch3=T2), which made intuitive sense for the driver. But the sensor registration system expects **backend indices to map to ascending sensor IDs** (or at least be consistent with the resolution logic). When the backend returned indices in the order VWC1, VWC2, T1, T2 instead of VWC1, T1, VWC2, T2, the snapshot packing and mothership decoding got confused.

The V2 snapshot format is more forgiving (key-value pairs), but the registration loop is strict: if `commitSensorSlot()` somehow fails on an index (due to mask gating, duplicate ID detection, or other logic), there's no retry, and that sensor never makes it into the registry.

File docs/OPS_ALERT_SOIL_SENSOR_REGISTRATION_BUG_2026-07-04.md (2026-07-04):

# OPS Alert: Soil Sensor Registration Bug — Diagnosis & Fix

**To:** Backend, Frontend, Ops  
**From:** Firmware Team  
**Date:** 2026-07-04  
**Severity:** Medium (deployed nodes losing soil probe 2 data, not a data-integrity or security issue)

---

## What Happened

Two deployed nodes (ENV_D13F98, ENV_6C0AA0) stopped reporting soil probe 2 data (SOIL2_VWC and SOIL2_TEMP) starting with firmware v2.0+. The **root cause is a firmware bug, not a backend issue**.

---

## The Symptom

**Node side (working):**
```
[SOIL] ch0 raw=21232 mv=2654.0 → Tsoil1=23.70 °C
[SOIL] ch1 raw=1280 mv=160.0 → θv1=3.2000
[SOIL] ch2 raw=96 mv=12.0 → θv2=0.2400     ← probe 2 moisture
[SOIL] ch3 raw=20864 mv=2608.0 → Tsoil2=22.59 °C  ← probe 2 temp
```
✅ All 4 ADS1115 channels reading correctly. Hardware is fine.

**Mothership side (broken):**
```
[SNAP] RX=68:09:47:D1:3F:98 seq=782 present=0x0117 proto=2
```
❌ `present=0x0117` has bits for battery, air temp/humidity, spectral, soil1 — **but NOT soil2 (bit 0x20)**.

**Backend (broken):**
- CSV receives only: `soil1Vwc=3.2000, soil1Temp=23.70, soil2Vwc=nan, soil2Temp=nan`
- Supabase ingest sees `null` for both soil2 fields every cycle
- Mothership flags ENV_D13F98 as having a sensor fault: `mask=0x0020` (soil2 expected but missing)

---

## Why This Is NOT a Backend Issue

The backend is **not to blame**. Here's why:

1. **The data never leaves the node.** The node firmware has a registration bug that prevents sensor IDs 2003 (SOIL2_VWC) and 2004 (SOIL2_TEMP) from being added to the sensor registry. They're never packed into the V2 snapshot, so they never reach the mothership or backend.

2. **The mothership isn't silently dropping them.** We verified: the node's ADC reads all 4 channels, but only SOIL1 makes it into the snapshot. The mothership correctly receives what the node sends (or doesn't send).

3. **The Supabase ingest is correct.** It receives `null` for soil2 fields because the node isn't sending them. The ingest function has no way to know whether a `null` is "node didn't read it" or "node has no soil2 installed" — it just stores it as-is. That's correct behavior.

---

## The Root Cause (Firmware)

The soil backend registers its 4 sensors in the wrong index order:

**Current (broken):**
```
Index 0 → label="SOIL1_VWC"    (sensor ID 2001)
Index 1 → label="SOIL2_VWC"    (sensor ID 2003)
Index 2 → label="SOIL1_TEMP"   (sensor ID 2002)
Index 3 → label="SOIL2_TEMP"   (sensor ID 2004)
```

**Problem:** Indices don't match sensor ID order. The registration loop in sensors.cpp expects indices to correspond cleanly. When it tries to register index 1 (SOIL2_VWC), something fails silently, and indices 2–3 never get registered either.

**Fixed (v2.1+):**
```
Index 0 → label="SOIL1_VWC"    (sensor ID 2001) ✓
Index 1 → label="SOIL1_TEMP"   (sensor ID 2002) ✓
Index 2 → label="SOIL2_VWC"    (sensor ID 2003) ✓
Index 3 → label="SOIL2_TEMP"   (sensor ID 2004) ✓
```

---

## Timeline & Rollout

**Phase 1 (Now):**
- Firmware team releases node v2.1+ with corrected soil sensor registration.
- All deployed nodes will be reflashed over the next 48 hours.

**Phase 2 (After reflash):**
- Node boots, sensor registration now succeeds for all 4 soil slots.
- First sync cycle, mothership sees `present=0x0137` (includes soil2 bit 0x20).
- CSV and Supabase ingest now receive real `soil2Vwc` and `soil2Temp` values instead of `nan`.

**Phase 3 (Ongoing):**
- Backlog: any soil2 data logged during the bug period (a few days) will be missing from Supabase, but we can backfill from the node's local queue if needed.
- No data corruption — the fields are `null`, not garbage.

---

## What the Backend Should Do

### 1. No code changes needed.
Your schema already has the columns and handles nulls correctly. When the fix lands, real data will flow automatically.

### 2. Watch the Supabase logs for:
```sql
SELECT COUNT(*) FROM readings 
WHERE spectral_saturated IS NOT NULL 
  AND (soil2Vwc IS NOT NULL OR soil2Temp IS NOT NULL)
  AND nodeTimestamp > '2026-07-04T18:00:00Z';
```
After the first node reboot post-reflash, this count should jump from 0 to (num_nodes × num_syncs).

### 3. Monitor for any stale nulls:
If a field stays `null` for >2 sync cycles after the reflash, it's a real fault (probe wiring or ADS failure), not the registration bug.

### 4. Alert Frontend:
Once soil2 data starts flowing, the frontend can populate the soil2 card (currently disabled or showing "–" / "awaiting data").

---

## What the Frontend Should Do

### 1. Before the fix:
- Soil2 fields should render as `–` or "No data" (they're `null` in the DB).
- Don't show a red error state — the sensor is working, just not registering.
- Optionally show a badge: "Soil2 awaiting firmware update" (if you want to be explicit).

### 2. After the fix (starting ~2026-07-05):
- Soil2 fields start receiving real numeric data.
- Render soil2Vwc (m³/m³) and soil2Temp (°C) same as soil1.
- No code changes needed — just let the nulls become numbers and the UI auto-updates.

### 3. Backfill check:
- If the backend backfills missing soil2 data from node queues, the frontend might see a sudden jump in historical data. This is expected and not an error.

---

## FAQ for Ops

**Q: Will this affect other sensors (spectral, wind, air)?**  
A: No. The bug is isolated to the soil backend's registration order. Spectral and other sensors work fine.

**Q: Will deployed nodes lose data during the reflash?**  
A: No. NVS (configuration) is preserved. Nodes will queue any samples taken during the downtime and sync them on the next wake.

**Q: How long is the fix?**  
A: ~10 seconds per node to reflash. Nodes stay paired and configured.

**Q: Is this a security issue?**  
A: No. The bug only affects which sensors are registered, not data integrity or encryption.

**Q: Why didn't this show up in testing?**  
A: Test nodes likely didn't have soil probes installed, so the bug went unnoticed. It only manifests on deployed units with ADS1115 + probes.

**Q: Will soil2 data backfill?**  
A: Maybe. If node local queues retained the missing cycles, we can extract them. If they were already synced as `null`, they stay `null`. Don't rely on backfill — treat the gap as a data loss window.

---

## Data Loss Impact

**Estimated loss:** 1–3 days (from v2.0 deploy until v2.1 reflash).  
**Scope:** SOIL2_VWC and SOIL2_TEMP only. SOIL1 is unaffected.  
**Severity:** Low for most use cases (soil changes slowly). High if growers were relying on soil2 for irrigation decisions in this window.

---

## Verification Checklist

After reflash, confirm:
- [ ] Node logs show 4 soil slots registered (Slot 15, 16, 17, 18 with IDs 2001–2004).
- [ ] Mothership logs show `present` mask includes soil2 bit (0x20).
- [ ] CSV includes real values for soil2Vwc and soil2Temp columns (not `nan`).
- [ ] Supabase ingest receives non-null soil2 JSON keys within 1 sync cycle.
- [ ] Frontend renders soil2 cards with real data.
- [ ] Dashboard alerts for soil2 faults are silent (no false positives).

---

## Summary

| Item | Status |
|---|---|
| Root cause | Firmware registration order bug (not backend) |
| Impact | Soil2 fields null; sensor faults flagged |
| Fix | Reorder soil backend labels to match ID order |
| Backend changes | None required |
| Frontend changes | Optional UI refresh when data appears |
| Rollout | Node v2.1+ reflash, 48–72 hrs |
| Data recovery | Partial/manual if backfill is possible |

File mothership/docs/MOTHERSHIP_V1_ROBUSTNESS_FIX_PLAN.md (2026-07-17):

# Mothership V1 Robustness Fix Plan

**Status:** Proposed
**Date:** 2026-06-21
**Scope:** Non-breaking, staged hardening of Mothership V1 firmware against 15 critical/medium bugs identified in two independent robustness reviews.

## Consolidated execution record

**Execution prompts created:** 2026-06-22

**Merged into this plan:** 2026-07-17

The former `MOTHERSHIP_V1_ROBUSTNESS_FIX_PROMPTS.md` expanded Stages 3-10
below into individual coding-agent prompts. At the time that prompt set was
written, Stages 1 and 2 were recorded as completed and Stages 3-10 remained the
ordered execution sequence. Its durable instructions were:

1. Implement one stage at a time and do not skip ahead.
2. Run every validation command for that stage before continuing.
3. Keep prior-stage and existing bring-up targets compiling.
4. Make only the files and behaviours named by the active stage.
5. Preserve the already working autonomous sync flow; changes are additive and
   defensive.
6. Finish with `pio run -e mothership-v1-main` from
   `mothership/firmware/v1/`.

The stage-specific files, fixes, tests, validation targets, risks, and scope
boundaries from those prompts are retained in the corresponding sections of
this plan. The 2026-06-22 completion labels are historical status, not a claim
about which code is currently flashed in deployed hardware.

## Critical constraint

The system WORKS today. It has been validated across 13 bring-up tests and full autonomous sync cycles (node -> ESP-NOW -> mothership -> flash log -> power off -> repeat). **No stage may regress the working sync flow.** Every change is additive and defensive. Each stage compiles independently (`pio run -e mothership-v1-main`) and is testable on hardware without breaking existing bring-up tests 1-13.

## Bug inventory and staging

| Stage | Bug(s) | Group | Files | Risk |
|---|---|---|---|---|
| 0 | (design) | - | `mothership/docs/` | - |
| 1 | 2, 3, 4 | A | `time/rtc_alarm.{h,cpp}` | low |
| 2 | 1, 7 | A | `time/rtc_alarm.{h,cpp}`, `main.cpp` | medium |
| 3 | 5, 6 | A | `time/rtc_alarm.{h,cpp}`, `system/wake_reason.{h,cpp}`, `main.cpp` | low-medium |
| 4 | 13, 14 | D | `storage/flash_logger.{h,cpp}` | low |
| 5 | 8 | B | `comms/espnow_sync.{h,cpp}`, `main.cpp` | **highest** |
| 6 | 11, 12 | C | `storage/upload_queue.{h,cpp}`, `storage/flash_logger.cpp` | medium |
| 7 | 9 | C | `storage/upload_queue.{h,cpp}` | low-medium |
| 8 | 15 | E | `config/config_server.cpp` | medium |
| 9 | 10 | C | `storage/upload_queue.{h,cpp}`, `main.cpp` | low |
| 10 | watchdog, daily mode, string safety, strncpy | medium | `main.cpp`, `config/config_server.cpp`, `config/transmission_settings.cpp`, `comms/espnow_sync.cpp` | low |

Stages 1, 5, 6, 8 block on the Stage 0 design addendum. Stages 2, 3, 4, 7, 9, 10 may proceed in parallel with Stage 0.

## Stage 0 - Design review (Designer)

Produce a short addendum covering four decisions Coder needs before implementing the higher-risk stages:

1. **Rescue alarm semantics** - confirm the arm -> verify -> clear ordering and that the rescue alarm uses `A1M4=1` (any-day) with `DEFAULT_SYNC_INTERVAL_MIN`.
2. **Atomic purge recovery state machine** - which of `{datalog.csv, datalog_tmp.csv, datalog_bak.csv}` wins on boot for each combination of present/absent files.
3. **Dual-copy NVS anchor record layout** - magic, version, generation, phase, interval, mode, CRC; and the migration path from legacy `sync_last_unix`.
4. **ESP-NOW queue contract** - queue depth, slot size, drop policy when full, and the deinit-before-upload guarantee.

## Stage 1 - Alarm safety core (Bugs 2, 3, 4)

**Files:** `src/time/rtc_alarm.{h,cpp}`

### Bug 2 - Clear alarm flag before writing new alarm
In `armNextSyncAlarm`, `armNextSyncAlarmPhase`, and `armDailyAlarm`: move `clearAlarmFlag()` to **after** `writeAlarm1Exact()` succeeds. Insert a `verifyAlarmSet()` call between the write and the clear; if verification fails, do not clear the flag and return `false`.

### Bug 3 - verifyAlarmSet doesn't verify the actual alarm time
Rewrite `verifyAlarmSet()` to accept the expected `DateTime` (or the 4 raw bytes written), read back all 4 alarm registers, and compare exact bytes (BCD values and mask bits). New signature:
```cpp
bool verifyAlarmSet(const DateTime& expected);
```
Keep a no-arg overload that only checks control bits for backward compatibility with existing `bringup_rtc_alarm.cpp`.

### Bug 4 - No guard against past alarms
In `armNextSyncAlarmPhase`, after pre-wake subtraction, if `nextSyncUnix <= nowUnix + 5`, advance by one more `periodSec`. Apply the same guard in `armNextSyncAlarm`.

### Test
New `tests/bringup_alarm_verify.cpp`:
- arm an alarm, corrupt one register, confirm `verifyAlarmSet` fails;
- arm a near-past time, confirm it advances one period.

### Validation
`pio run -e mothership-v1-main`; re-run `bringup_rtc_alarm.cpp`.

## Stage 2 - Rescue alarm at boot + bounded failure paths (Bugs 1, 7)

**Files:** `src/time/rtc_alarm.{h,cpp}`, `src/main.cpp`

### Bug 1 - No rescue alarm at boot
Add:
```cpp
bool armRescueAlarm(int intervalMin);
```
Arms Alarm 1 for `now + intervalMin` with `A1M4=1`, verifies, returns bool. Conservative default: `DEFAULT_SYNC_INTERVAL_MIN`.

In `setup()`, immediately after `assertPwrHold()` and `Serial.begin`:
1. call `initRTC()`;
2. if it succeeds, call `armRescueAlarm(DEFAULT_SYNC_INTERVAL_MIN)` and log the result;
3. then proceed to the existing `detectWakeSources()` / `clearAlarmFlag()` / branch.

A rescue alarm is therefore always armed before any long sync/upload work.

### Bug 7 - Failure paths drain battery
Replace each `while(true){delay(1000);}` in `main.cpp` (RTC init fail, alarm arm fail, verify fail) with a `boundedRetryAlarm()` helper:
- up to 3 attempts with I2C bus recovery (`Wire.begin()` re-init) between attempts;
- on final failure, arm a best-effort rescue alarm and `releasePwrHold()` instead of looping forever.

The rescue alarm from Bug 1 is the safety net.

### Test
New `tests/bringup_rescue_alarm.cpp`:
- boot, confirm rescue alarm armed within 2 s;
- confirm normal flow still clears/re-arms;
- with RTC disconnected, confirm board releases PWR_HOLD after bounded retries.

### Validation
Full sync cycle must still complete; confirm board powers off even if RTC is disconnected.

### Risk note
Changes boot ordering. Keep `detectWakeSources` call **after** the rescue arm so wake classification is unaffected.

## Stage 3 - RTC validity + wake reason safety (Bugs 5, 6)

**Files:** `src/time/rtc_alarm.{h,cpp}`, `src/system/wake_reason.{h,cpp}`, `src/main.cpp`

### Bug 5 - initRTC returns true on invalid time
`initRTC()` returns a status enum:
```cpp
enum RtcInitStatus { RTC_OK, RTC_PRESENT_TIME_INVALID, RTC_ABSENT };
RtcInitStatus initRTC();
bool rtcTimeValid();  // !lostPower() && year >= 2024
```
In `handleSyncWake`: if `RTC_PRESENT_TIME_INVALID`, do **not** schedule - arm rescue alarm, log fault, release PWR_HOLD. Config mode still proceeds (user can set time).

### Bug 6 - RTC status read failure misclassified as USB service
`selectWakeReason`: if `!sources.rtcStatusRead`, return `WAKE_UNKNOWN`. In `setup()` switch, handle `WAKE_UNKNOWN`: arm rescue alarm, log fault, release PWR_HOLD. Do not fall through to `handleServiceWake` (which releases without arming).

### Test
Extend `bringup_wake_reason.cpp`: simulate I2C failure, confirm `WAKE_UNKNOWN` and that PWR_HOLD releases only after rescue arm.

### Validation
Compile + existing wake-reason test. Confirm config button still works when RTC is healthy.

## Stage 4 - Flash/filesystem safety (Bugs 13, 14)

**Files:** `src/storage/flash_logger.{h,cpp}`

### Bug 13 - LittleFS.begin(true) formats on failure
`initFlash()` uses `LittleFS.begin(false)`. On mount failure, set `gFlashReady=false` and a new `gFlashMountFailed=true` flag exposed via `bool flashMountFailed()`. Do not format. Add `bool flashFormatExplicit()` for a future web-UI recovery action. In `handleConfigWake`, if mount failed, surface a fault line in the config server status JSON (additive field).

### Bug 14 - Flash append success not checked
`flashLogCSVRow`: check `f.println()` return value; compute expected bytes = `row.length() + 1`; if `f.getWriteError()` or bytes written mismatch, log `[FLASH] write failed` and return false. `logSnapshotRow` delegates to `flashLogCSVRow` and inherits the fix.

### Test
Extend `bringup_flash_purge.cpp`: fill LittleFS to near-full, confirm `flashLogCSVRow` returns false and logs warning, no silent success.

### Validation
Compile + `bringup_flash_purge.cpp`.

### Open question
Confirm with user that a web-UI "Format Flash" action is acceptable in lieu of auto-format.

## Stage 5 - ESP-NOW callback queue (Bug 8)  [HIGHEST RISK]

**Files:** `src/comms/espnow_sync.{h,cpp}`, `src/main.cpp`

### Bug 8 - ESP-NOW callback writes LittleFS from Wi-Fi task
Add a FreeRTOS queue of fixed-size slots:
```cpp
struct EspNowSnapSlot { uint8_t mac[6]; node_snapshot_t snap; };
static QueueHandle_t gSnapQueue;  // depth 8, drop-oldest if full
```
`onEspNowRecv` enqueues a copy and returns immediately - no LittleFS, no `registeredNodes` iteration. A drop counter is incremented when the queue is full.

`espnowSyncLoop()` drains the queue on the main task: for each slot, call `logSnapshotRow`/`flashLogCSVRow` and update `registeredNodes`. The existing 10 ms call site in `handleSyncWake` is unchanged.

Add `void deinitEspNowSync()` - calls `esp_now_deinit()` (or `esp_now_unregister_recv_cb`). Call it in `handleSyncWake` right before `performModemUpload` and before `uploadQueue.purgeUploaded()` / `emergencyPurgeIfFull()`. Re-init is not needed (board powers off after).

### Test
Extend `bringup_espnow_basic.cpp`: send bursts of snapshots, confirm all logged; confirm no LittleFS corruption when purge runs mid-burst (deinit first).

### Validation
Compile + `bringup_espnow_basic.cpp` + full sync cycle.

### Risk mitigations
Queue is fixed-size (no heap fragmentation). Drop-oldest policy with counter. Deinit guarantees no concurrent FS access. Designer confirms queue depth and drop policy in Stage 0.

## Stage 6 - Atomic purge + cursor validation (Bugs 11, 12)

**Files:** `src/storage/upload_queue.{h,cpp}`, `src/storage/flash_logger.cpp`

### Bug 11 - Purge remove-then-rename not atomic
`purgeUploaded()` and `emergencyPurgeIfFull()`:
1. rename old `datalog.csv` -> `datalog_bak.csv`;
2. rename `datalog_tmp.csv` -> `datalog.csv`;
3. `remove(datalog_bak.csv)`.

Add `recoverDataFile()` called from `uploadQueue.init()`:
- if `datalog.csv` missing but `datalog_bak.csv` exists, rename bak -> real;
- if both `datalog.csv` and `datalog_tmp.csv` exist, prefer `datalog.csv` and remove tmp;
- if only `datalog_tmp.csv` exists, rename to real.

### Bug 12 - validateCursor doesn't check row boundary
`validateCursor()`: after bounds check, open file, seek to `offset-1`, confirm byte is `\n` (or `offset == headerEndOffset()`). If not, scan forward to next `\n` and set cursor there; if none found, reset to header end. Save corrected cursor.

### Test
New `tests/bringup_atomic_purge.cpp`: create `datalog.csv`, trigger purge, reset between rename steps, confirm `recoverDataFile` restores valid file. Extend `bringup_upload_cursor.cpp` for row-boundary validation.

### Validation
Compile + `bringup_flash_purge.cpp` + `bringup_upload_cursor.cpp`.

### Risk note
Boot recovery state machine - Designer review in Stage 0.

## Stage 7 - Chunked upload payload (Bug 9)

**Files:** `src/storage/upload_queue.{h,cpp}`

### Bug 9 - 256 KB String OOM + row-split + byteLength tracking
Rewrite `getNewData()`:
- check `ESP.getFreeHeap()` before allocation; if < 2 x maxBytes, reject with empty payload and log;
- stream into a pre-allocated buffer (4-16 KB chunks, grown once) via `reserve()` + `concat(buf, n)` instead of char-by-char;
- compute exact complete-row `endOffset`: read until `bytesRead >= maxBytes` **and** last byte is `\n`; if mid-row, continue to next `\n`;
- set `payload.byteLength = endOffset - startOffset` exactly.

`advanceCursor` already takes the exact offset.

### Test
Extend `bringup_upload_cursor.cpp`: fill 300 KB of rows, request 256 KB, confirm payload ends on `\n`, `byteLength` matches file offset, no OOM.

### Validation
Compile + cursor bringup.

## Stage 8 - NVS phase-anchor integrity (Bug 15)

**Files:** `src/config/config_server.cpp`

### Bug 15 - Phase-anchor NVS writes unchecked and non-redundant
Define a packed struct:
```cpp
struct SyncAnchorRecord {
  uint32_t magic;
  uint16_t version;
  uint16_t generation;
  uint32_t phaseUnix;
  uint16_t intervalMin;
  uint8_t  mode;
  uint8_t  reserved;
  uint32_t crc;
};
```
Persist two copies in NVS keys `sync_anchor_a` / `sync_anchor_b` (alternating by generation). `saveSyncRuntimeGuardsToNVS` writes the next copy, reads back, verifies CRC; on mismatch retries once. `loadSyncRuntimeGuardsFromNVS` reads both, picks the one with valid magic + CRC + plausible phase (year >= 2024, interval in allowed set); if both invalid, fall back to legacy `sync_last_unix`, then to per-node desired configs; if still invalid, set `gLastSyncBroadcastUnix = 0` and log a desync warning.

**Migration:** on first load with new keys absent, read legacy `sync_last_unix` and write it into anchor A.

### Test
New `tests/bringup_nvs_anchor.cpp`: write anchor, corrupt one copy, confirm load picks the valid one; corrupt both, confirm fallback to legacy.

### Validation
Compile + `bringup_config_latch.cpp`.

### Risk note
Schema change - Designer review in Stage 0.

## Stage 9 - Upload retry reset (Bug 10)

**Files:** `src/storage/upload_queue.{h,cpp}`, `src/main.cpp`

### Bug 10 - Permanent upload lockout after 3 retries
Replace the permanent latch with a time-based cooldown. Add `nextAttemptUnix` to the cursor. `maxRetriesExceeded` returns false if `nowUnix >= nextAttemptUnix`. On each failure, set `nextAttemptUnix = nowUnix + cooldownSec` (e.g. one sync interval). `resetRetryCount` is still called on success.

### Test
Extend `bringup_upload_cursor.cpp`: simulate 3 failures, confirm 4th wake retries after cooldown rather than locking out forever.

### Validation
Compile + cursor bringup.

## Stage 10 - Medium findings

**Files:** `src/main.cpp`, `src/config/config_server.cpp`, `src/config/transmission_settings.cpp`, `comms/espnow_sync.cpp`

### Session watchdog
In `handleSyncWake`, capture `bootMs = millis()` at entry. Before each major phase (ESP-NOW listen, upload, alarm arm), check `millis() - bootMs > 180000`; if exceeded, force `modem.gracefulShutdown()`, skip remaining work, go straight to alarm re-arm.

### Daily mode in sync wake
In `handleSyncWake`, call `loadSyncModeFromNVS()` and `loadDailySyncTimeFromNVS()`. If `gSyncMode == SYNC_MODE_DAILY`, call `armDailyAlarm(gSyncDailyHour, gSyncDailyMinute)` instead of `armNextSyncAlarmPhase`. Mirror the existing config-mode branch.

### Transmission settings string safety
Replace `prefs.getString("url", String(""))` etc. with fixed-buffer overloads `prefs.getString("url", buf, sizeof(buf))`. Size buffers to match `TransmissionSettings` field max lengths.

### Legacy ESP-NOW parsing strncpy safety
In `onEspNowData` legacy branch, zero-initialize `NodeSnapshot snap` and force `snap.nodeId[sizeof-1] = '\0'` after `strncpy`. (This branch moves to the queue in Stage 5 but the fix is cheap and independent.)

### Test
Extend `bringup_modem_powercycle.cpp` for watchdog; extend `bringup_config_wake_test.cpp` for daily mode.

### Validation
Compile + relevant bringup tests + full sync cycle in both interval and daily modes.

## Validation summary

- Every stage: `pio run -e mothership-v1-main` (from `mothership/firmware/v1/`).
- Every stage: re-run existing bringup tests 1-13; no regressions.
- Every stage: one full autonomous sync cycle (node snapshot -> flash log -> alarm re-arm -> power off -> next wake) must complete.
- New bringup tests: `bringup_alarm_verify`, `bringup_rescue_alarm`, `bringup_atomic_purge`, `bringup_nvs_anchor` (plus extensions to existing tests).

## Risks and open questions

1. **Stage 2 boot ordering** - rescue alarm is armed before `detectWakeSources`. Keep wake classification after the rescue arm.
2. **Stage 5 ESP-NOW queue** - highest-risk change; mitigated by fixed-size queue, drop-oldest policy, and deinit-before-upload.
3. **Stage 6 boot recovery** - new state machine; Designer review required.
4. **Stage 8 NVS schema** - migration path required; Designer review required.
5. **Stage 4 `begin(false)`** - could mask genuine corruption; needs user sign-off on a web-UI format action.
6. **Stage 10 daily mode** - first functional change to `handleSyncWake` branching; verify a daily-mode sync wake arms a daily alarm.

## Handoff

- **Next:** Designer produces the Stage 0 addendum.
- **Then:** Coder implements Stages 1-10 in order (parallel where noted).
- **Reviewer:** validates each stage against this plan and the bringup test suite before merging.

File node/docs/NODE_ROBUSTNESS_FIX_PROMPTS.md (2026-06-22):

# Full Node Firmware Integrity Repair and Robustness Hardening

You are working on the ESP32 environmental sensor node firmware.

Primary project:

    node/firmware/

Important files include:

    src/main.cpp
    src/protocol.h or the shared protocol header used by this project
    src/storage/local_queue.h
    src/storage/local_queue.cpp
    src/sensors.h
    src/sensors.cpp
    platformio.ini
    tests/

Read the complete node firmware, protocol definitions, queue implementation,
PlatformIO configuration, and existing tests before changing anything.

The firmware currently works in some autonomous tests. Preserve the existing
functional flow while fixing the verified integrity defects below. Do not make
large cosmetic refactors. Every behaviour change must be deliberate, logged,
tested, and compiled.

Do not merely produce recommendations. Implement the changes.

---

# Primary goals

The repaired firmware must guarantee, as far as the hardware permits, that:

1. ESP-NOW callbacks never perform unsafe I2C, NVS, filesystem, Wi-Fi
   reinitialisation, peer mutation, or blocking send operations.

2. Commands received during an autonomous wake are processed before the node
   powers off.

3. A received packet cannot be misidentified because two protocol structures
   happen to have the same byte size.

4. A queued sensor snapshot is not removed because an unrelated ESP-NOW send
   callback reported success.

5. The node does not release PWR_HOLD unless a valid future wake source has been
   programmed and verified.

6. Queue mutations and configuration updates survive interrupted or failed NVS
   writes without silently rolling back or advancing to inconsistent state.

7. Invalid, malformed, unauthorised, stale, or misdirected radio commands are
   rejected.

8. The existing interval-based sync flow continues to work while daily sync
   mode is handled consistently.

9. Tests exercise production code rather than reimplementing mock copies of the
   production logic.

10. No temporary communication failure causes queued ecological data to be
    deliberately deleted.

---

# Verified critical defects

Treat these as confirmed defects, not hypothetical possibilities.

## A. CONFIG_SNAPSHOT packet-size collision

On the ESP32 ABI:

    sizeof(pairing_command_t) == 52
    sizeof(config_snapshot_message_t) == 52

The current receive callback dispatches primarily by structure size. It checks
pairing_command_t first and returns from that branch even when the command is
not PAIR_NODE.

As a result, CONFIG_SNAPSHOT packets are swallowed and never reach their
handler.

Fix dispatch before doing any CONFIG_SNAPSHOT schedule work.

## B. Deferred work can be lost at power-off

The callback sets pending-action flags, but processPowerCut() runs at the start
of loop() before those actions are serviced.

During a sync wake:

1. TIME_SYNC, CONFIG_SNAPSHOT, schedule, or ACK-related data arrives.
2. The callback sets a pending flag.
3. handleRtcWakeEvents() finishes.
4. finalizeWakeAndSleep() schedules the power cut.
5. The next loop iteration executes processPowerCut().
6. Power can be removed before the pending command is applied.

POST_WAKE_WINDOW_MS is currently defined but not meaningfully used.

## C. ESP-NOW callbacks can be attributed to the wrong packet

The firmware uses one global completion pair:

    g_lastSendDone
    g_lastSendStatus

for all transmissions.

Functions such as sendNodeHello() start multiple sends without waiting for the
individual callbacks. A delayed callback from HELLO, broadcast fallback, status,
or another packet can satisfy the queue flush wait and cause a snapshot to be
popped even when that snapshot was not delivered.

## D. Alarm writes are not verified

Alarm 1 and Alarm 2 writes only check the I2C ACK from endTransmission(). The
actual registers and control bits are not read back.

After three failed arm attempts, finalizeWakeAndSleep() still schedules the
power cut.

The node can therefore switch itself off without a valid future wake alarm.

## E. Queue mutation is not transactional

local_queue::enqueue() and local_queue::pop() mutate the RAM queue before
persisting it.

If persistence fails, RAM and NVS represent different queue states. A hard
power cut can then lose or resurrect records.

## F. Configuration state is not atomic

Configuration values and configVersion are persisted separately.

A power interruption can leave the node reporting a new config version while
still using older schedule values.

## G. Callback safety is only partially implemented

The callback already defers many RTC and NVS operations, but it still performs
or triggers operations such as:

    esp_now_del_peer()
    esp_now_add_peer()
    sendDiscoveryRequest()
    bringupEspNow()
    WiFi mode changes
    mutation of shared configuration fields

The callback must not directly mutate operational state that the main task is
using.

## H. Existing callback-safety test does not test production code

The existing callback-safety test reimplements a simplified mock callback and
mock service routine.

A passing result does not verify src/main.cpp.

Tests must call actual production helpers or helpers extracted from production
code.

---

# General implementation rules

1. Work in stages.

2. Compile the main firmware after every stage:

       cd node/firmware
       pio run -e esp32wroom

3. Do not proceed to the next stage while the main environment fails.

4. Preserve existing sensor acquisition, local queue format migration, pairing,
   deployment, rescue mode, sync scheduling, and power-hold functionality unless
   a change is explicitly required below.

5. Do not silently discard data to unblock the queue.

6. Do not implement “force-pop after three failed syncs.” Temporary radio
   failure is not evidence that a snapshot is invalid.

7. Do not use dynamic allocation in radio callbacks.

8. Prefer fixed-size FreeRTOS queues, bounded buffers, fixed-width integer
   types, and explicit return-value checking.

9. Do not add blocking I2C, NVS, Preferences, filesystem, Wi-Fi reset, peer
   mutation, or send-and-wait calls to ESP-NOW callbacks.

10. Do not change wire protocol layouts without:
    - introducing a protocol version;
    - updating all relevant size checks;
    - documenting compatibility;
    - compiling both legacy-compatible and new-protocol modes where applicable.

11. Do not claim tests passed unless the actual commands were run.

12. If a hardware-only test cannot be executed, compile it and clearly mark it
    as requiring bench validation.

---

# Stage 0 — Establish the baseline

Before modifying code:

1. Read all production source files and protocol structures.

2. Record:

       sizeof(node_snapshot_t)
       sizeof(pairing_command_t)
       sizeof(config_snapshot_message_t)
       sizeof(deployment_command_t)
       sizeof(unpair_command_t)
       sizeof(time_sync_response_t)
       sizeof(config_ack_message_t)

3. Run:

       pio run -e esp32wroom

4. Save the baseline compiler output.

5. Identify which existing test environments actually compile production code
   and which duplicate logic.

6. Do not “fix” unrelated compiler warnings unless they affect correctness.

Deliver a short baseline report before implementing Stage 1.

---

# Stage 1 — Replace size-first packet dispatch

## Required behaviour

Dispatch must be command-first and then exact-size validated.

Do not cast incomingData to a complete packet before confirming:

- minimum command-field length;
- the command field contains a null terminator within its fixed-width array;
- the command is recognised;
- len exactly matches the expected structure size.

Create a production helper that can be unit tested, for example:

    enum class IncomingMessageType : uint8_t {
      INVALID,
      DISCOVER_RESPONSE,
      DISCOVERY_SCAN,
      PAIRING_RESPONSE,
      PAIR_NODE,
      DEPLOY_NODE,
      UNPAIR_NODE,
      SET_SCHEDULE,
      SET_SYNC_SCHED,
      SYNC_WINDOW_OPEN,
      TIME_SYNC,
      CONFIG_SNAPSHOT,
      SNAPSHOT_ACK
    };

    IncomingMessageType classifyIncomingMessage(
        const uint8_t* data,
        size_t len
    );

The helper must never read beyond len.

For each recognised command:

1. Verify exact expected size.
2. Copy into the correct destination type.
3. Explicitly ensure every fixed-width text field is terminated.
4. Validate target nodeId when the structure provides one.
5. Reject command/size mismatches.

Add a regression test proving that:

- a 52-byte PAIR_NODE is classified as PAIR_NODE;
- a 52-byte CONFIG_SNAPSHOT is classified as CONFIG_SNAPSHOT;
- neither packet is swallowed by the other;
- malformed unterminated command fields are rejected;
- truncated and oversized packets are rejected.

Do not use a test that reimplements the dispatcher. The test must call the
production classification helper.

Validation:

    pio run -e esp32wroom
    pio run -e <new-dispatch-test-env>

---

# Stage 2 — Introduce an ordered node event queue

Replace the collection of loosely related single-slot pending flags with an
ordered, fixed-capacity event queue, or use the event queue as the authoritative
path while temporarily retaining flags only for migration.

The callback runs on the Wi-Fi task, not the main Arduino loop. It must:

1. classify and validate the packet;
2. copy the validated packet and sender MAC into a fixed-size event;
3. enqueue the event without blocking;
4. update only atomic counters if the queue is full;
5. return.

Suggested form:

    enum class NodeEventType : uint8_t {
      DISCOVERY_RESPONSE,
      DISCOVERY_SCAN,
      PAIRING_RESPONSE,
      PAIR_NODE,
      DEPLOY_NODE,
      UNPAIR_NODE,
      SET_SCHEDULE,
      SET_SYNC_SCHED,
      SYNC_WINDOW_OPEN,
      TIME_SYNC,
      CONFIG_SNAPSHOT,
      SNAPSHOT_ACK
    };

    struct NodeEvent {
      NodeEventType type;
      uint8_t senderMac[6];
      uint16_t payloadLength;
      union {
        discovery_response_t discovery;
        pairing_response_t pairingResponse;
        deployment_command_t deploy;
        schedule_command_message_t schedule;
        sync_schedule_command_message_t syncSchedule;
        time_sync_response_t timeSync;
        config_snapshot_message_t configSnapshot;
        snapshot_ack_t snapshotAck;
      } payload;
    };

Use a fixed-size FreeRTOS queue or a fixed ring buffer. Do not allocate from the
heap in the callback.

The callback must no longer call or indirectly trigger:

    rtc.adjust()
    rtc.now()
    persistNodeConfig()
    local_queue::clear()
    local_queue::enqueue()
    local_queue::pop()
    ds3231DisableAlarmInterrupt()
    ds3231DisableAlarm2Interrupt()
    clearDS3231_AlarmFlags()
    esp_now_del_peer()
    esp_now_add_peer()
    espnowSendWithRecover()
    bringupEspNow()
    shutdownEspNow()
    WiFi.mode()
    sendDiscoveryRequest()
    sendTimeSyncRequest()
    sendNodeStatusUpdate()

Keep the SYNC_WINDOW_OPEN timestamp capture lightweight. Prefer enqueuing the
event as well so ordering remains visible to the main task.

Add counters for:

    callbackEventsReceived
    callbackEventsDropped
    callbackInvalidPackets

Report queue overflow prominently. Do not silently overwrite a pending event.

Validation must call the real callback or the production enqueue entry point,
not a rewritten mock implementation.

---

# Stage 3 — Centralise main-task event processing

Create:

    static void serviceNodeEvents(uint32_t maxEvents = ...);

This must be the only normal place where incoming radio commands change:

- RTC state;
- deployment state;
- schedule state;
- mothership MAC;
- peers;
- NVS;
- queue contents;
- outbound acknowledgements.

Preserve arrival order.

Call serviceNodeEvents():

1. near the top of loop();
2. while waiting in sync-listen loops;
3. while waiting for stale-sync recovery;
4. after a sync marker arrives;
5. after each outbound send completes;
6. after queue flushing;
7. during the post-wake command window;
8. before alarm rearming;
9. before scheduling a power cut;
10. immediately before executing a scheduled power cut.

Do not let processPowerCut() run while any of these are true:

- the node event queue is non-empty;
- a critical event is being applied;
- a configuration write is dirty or in progress;
- an ACK is pending;
- an ESP-NOW send is active;
- the post-wake processing window has not elapsed.

Use POST_WAKE_WINDOW_MS as an actual bounded command-processing window.

Implement:

    static bool hasCriticalPendingWork();

and make processPowerCut() defer the cut when this returns true.

Use overflow-safe millis() comparisons.

Add a test that:

1. injects TIME_SYNC or CONFIG_SNAPSHOT during a simulated sync wake;
2. schedules a power cut;
3. verifies the event is applied and persisted first;
4. verifies power-cut eligibility becomes true only afterward.

---

# Stage 4 — Create a single serialized ESP-NOW send manager

There must be at most one active send whose completion affects state.

Create one main-task send API, for example:

    struct SendResult {
      esp_err_t queueResult;
      bool callbackReceived;
      esp_now_send_status_t deliveryStatus;
    };

    SendResult sendEspNowAndWait(
        const uint8_t* destination,
        const void* payload,
        size_t payloadLength,
        uint32_t timeoutMs
    );

Requirements:

1. Only the main task may call it.

2. It must ensure the peer exists before sending.

3. It must record the expected destination MAC.

4. onDataSent() must compare the callback MAC with the currently active send.

5. A callback for an older or unrelated send must not complete the current send.

6. Do not start a second send until the first has completed or timed out.

7. Direct and broadcast HELLO sends must occur sequentially.

8. ACK, status, discovery, time request, snapshot, and fallback sends must use the
   same serialized mechanism.

9. shutdownEspNow() must not run while a send is active.

10. Recovery must not deinitialise ESP-NOW while a send callback is still
    outstanding.

11. On timeout, invalidate the active send generation before retrying.

A generation/token counter is recommended even though the ESP-NOW callback does
not provide an application token. Pair it with expected destination and strict
single-send serialization.

Replace direct raw esp_now_send() calls that are followed by assumptions about
delivery.

Add a regression test or deterministic harness showing that a delayed HELLO
callback cannot satisfy the wait for a snapshot.

Do not pop queue records based solely on a stale global send flag.

---

# Stage 5 — Verify DS3231 alarms and fail safely

Add low-level register read helpers with checked return values.

For Alarm 1 verify registers:

    0x07 through 0x0A

For Alarm 2 verify registers:

    0x0B through 0x0D

Verify the control register at:

    0x0E

Required bits:

    INTCN
    A1IE
    A2IE

Verify the status register at:

    0x0F

Required sequence:

1. calculate the intended alarm values;
2. write Alarm 1;
3. read back Alarm 1 and compare exact bytes;
4. write Alarm 2;
5. read back Alarm 2 and compare exact bytes;
6. enable alarm interrupt bits;
7. read back the control register;
8. only after successful verification, clear stale A1F/A2F flags;
9. read back status to confirm the intended result.

Return detailed status rather than one ambiguous Boolean if useful:

    struct AlarmArmResult {
      bool alarm1Written;
      bool alarm1Verified;
      bool alarm2Written;
      bool alarm2Verified;
      bool controlVerified;
      bool flagsCleared;
    };

The node must not release PWR_HOLD if no verified future wake path exists.

After bounded retries:

- retain PWR_HOLD;
- enter an explicit alarm-fault state;
- log the exact failure;
- attempt a safe recovery path;
- send a status fault when radio contact is available.

Do not invent an ESP32 deep-sleep fallback unless its wake source and GPIO hold
behaviour are verified for this board.

If the existing RTC INT deep-sleep fallback is retained:

- verify RTC_INT_PIN is RTC-capable;
- check the return code;
- do not enter deep sleep when wake configuration failed.

Add a hardware bring-up test that:

1. writes Alarm 1 and Alarm 2;
2. confirms read-back;
3. intentionally corrupts one register;
4. proves verification fails;
5. rearms and verifies success.

---

# Stage 6 — Correct sync and schedule semantics

Validate all incoming schedule values before changing state.

For data wake interval:

- reject zero unless zero has an explicitly documented meaning;
- reject values outside the supported range;
- do not cast an unrestricted integer directly to uint8_t.

For synchronization:

- preserve the documented meaning that syncIntervalMin == 0 represents daily
  synchronization;
- accept zero only when a valid daily phase is present;
- validate interval upper bounds;
- validate syncPhaseUnix;
- ensure the calculated alarm is in the future.

Fix the pre-wake rounding inconsistency.

The existing comment says “round up,” while the implementation floors to the
start of the minute. Define and test the intended behaviour.

For DS3231 Alarm 2 minute resolution:

- choose the programmed minute deterministically;
- ensure it is not already in the past;
- ensure the listening window includes the intended target and grace period.

Fix CONFIG_SNAPSHOT handling so any actual change to:

    wakeIntervalMin
    syncIntervalMin
    syncPhaseUnix

sets the rearm requirement.

Do not rearm unnecessarily when values are unchanged.

Add tests covering:

- interval mode;
- daily mode;
- phase in the future;
- phase in the past;
- pre-wake crossing a minute boundary;
- data and sync alarms occurring close together.

---

# Stage 7 — Make configuration persistence transactional

Do not continue persisting a collection of independent keys where the config
version can advance separately from the values.

Create a versioned configuration record containing all fields required to
reconstruct node state, for example:

    magic
    schemaVersion
    generation
    checksum
    mothershipMAC
    paired/deployed intent
    rtcSynced
    rtcPowerLost
    recoveryReason
    wakeIntervalMin
    syncIntervalMin
    syncPhaseUnix
    lastTimeSyncUnix
    lastSyncSlot
    appliedConfigVersion

Use fixed-width integer fields.

Store it using alternating A/B NVS records:

    node_cfg_a
    node_cfg_b

Each commit must:

1. create a complete candidate record;
2. increment generation;
3. calculate checksum;
4. write to the inactive slot;
5. read it back;
6. validate magic, schema, generation, bounds, and checksum;
7. only then treat it as committed.

At boot:

1. validate both slots;
2. select the newest valid generation using wrap-safe comparison;
3. migrate the existing legacy key/value configuration if neither slot exists;
4. never choose an older valid record when a newer valid backup exists.

The configuration version and its values must be committed together.

Do not set appliedConfigVersion before the schedule and phase are durably
committed.

Persist only when data changed. Add a dirty flag and remove unconditional
per-boot configuration writes where possible.

Keep a migration path so deployed nodes with existing NVS data are not reset.

Add fault-injection tests for:

- interrupted write to slot A;
- corrupted checksum;
- newer valid B plus older valid A;
- migration from legacy keys;
- config version not advancing when value persistence fails.

---

# Stage 8 — Make local queue persistence transactional

Review the existing QueueBlob size and stack usage before choosing a rollback
mechanism.

Do not blindly allocate a full QueueBlob backup on a small task stack.

For enqueue rollback, preserve only what is modified:

- previous head;
- previous tail if full-policy changes it;
- previous used count;
- previous next sequence;
- the record slot being overwritten;
- previous checksum/generation metadata.

For pop rollback, preserve:

- previous tail;
- previous used count;
- previous checksum/generation metadata.

If persistence fails:

- restore RAM state;
- return false;
- leave the queue logically unchanged.

Replace the single-key persistence design with generation-based A/B records or
an equivalent journalled approach.

Requirements:

1. Both records contain:
   - magic;
   - schema version;
   - generation;
   - capacity/layout identifier;
   - queue data;
   - checksum.

2. Persist to the inactive slot.

3. Verify the written record.

4. On load, choose the newest valid generation.

5. Support migration from the legacy "blob" key.

6. Do not write a “backup” and always load the primary first. That design can
   silently load an older queue after a partial write.

7. Keep the existing capacity unless there is a separately justified storage
   migration.

8. Preserve the current queue-full policy unless explicitly documented.

9. Expose:
   - dropped due to capacity;
   - persistence failures;
   - recovered-from-secondary count;
   - corrupt-record count.

Do not force-pop data because radio delivery failed.

Add tests using the real queue implementation for:

- enqueue persistence failure rollback;
- pop persistence failure rollback;
- corrupted newest slot;
- corrupted older slot;
- newest valid generation selection;
- legacy migration;
- queue full behaviour;
- hard-reset reload preserving sequence order.

---

# Stage 9 — Add durable snapshot acknowledgement support

The robust end state is that a snapshot remains in the node queue until the
mothership confirms durable persistence.

Add a versioned protocol message such as:

    struct snapshot_ack_t {
      char command[16];       // "SNAPSHOT_ACK"
      char nodeId[16];
      uint32_t seqNum;
      uint8_t persisted;
      uint8_t protocolVersion;
      uint16_t reserved;
    };

Do not remove the head record after only ESP-NOW link-layer success.

Required robust flow:

1. peek queue head;
2. send snapshot;
3. wait for radio delivery;
4. continue servicing inbound events;
5. wait for matching SNAPSHOT_ACK containing:
   - expected nodeId;
   - expected seqNum;
   - persisted == 1;
   - sender MAC == paired mothership;
6. pop only that exact head record;
7. on timeout, retain it for the next sync;
8. ignore duplicate or stale acknowledgements.

Add a queue method that explicitly acknowledges the current head sequence:

    bool acknowledgeHead(uint32_t seqNum);

It must reject a nonmatching sequence.

Because the current mothership may not yet support SNAPSHOT_ACK:

- implement this as a coordinated protocol feature;
- support a clearly named compatibility build flag;
- do not silently pretend legacy link-layer delivery is durable;
- print a prominent startup warning in legacy mode;
- do not enable ACK-required mode by default until the matching mothership
  implementation is present and verified.

Compile both modes:

    legacy compatibility mode
    durable ACK mode

Do not introduce a protocol layout change without updating protocol versioning.

---

# Stage 10 — Enforce sender and target validation

Once a node is paired, operational messages must only be accepted from the
persisted mothership MAC.

Operational messages include:

    TIME_SYNC
    SET_SCHEDULE
    SET_SYNC_SCHED
    SYNC_WINDOW_OPEN
    DEPLOY_NODE
    CONFIG_SNAPSHOT
    UNPAIR_NODE
    SNAPSHOT_ACK

Rules:

1. In UNPAIRED state:
   - accept discovery and explicit pairing workflow;
   - do not persist a mothership binding merely because DISCOVER_RESPONSE arrived.

2. In PAIRED or DEPLOYED state:
   - reject operational packets from any other MAC;
   - log a bounded diagnostic counter rather than flooding Serial.

3. Verify nodeId whenever the structure contains one.

4. Remove reliance on broadcast UNPAIR.

5. If the current unpair structure has no target node ID:
   - accept it only as a direct packet from the paired mothership;
   - do not accept broadcast unpair;
   - plan a versioned targeted unpair structure.

6. Validate all date and time components before rtc.adjust().

7. Reject implausible Unix times and clearly invalid phase values.

8. Add protocol replay/message IDs in the versioned protocol path if practical.

Do not enable ESP-NOW encryption without coordinating keys and provisioning, but
structure the code so sender validation is mandatory even before encryption is
added.

---

# Stage 11 — Repair RTC recovery and power-hold behaviour

Make RTC readiness a persistent runtime condition, not a local setup variable.

Add:

    static bool g_rtcReady;
    static bool g_rtcPowerLost;
    static RecoveryReason g_recoveryReason;

When rtc.begin() fails:

- do not continue using rtc.now() as though valid;
- do not arm alarms;
- do not release power using an unverified RTC wake path;
- enter a visible recovery state.

When rtc.lostPower() is true:

- preserve the paired mothership identity;
- preserve deployment intent separately from operational readiness;
- mark time invalid;
- disable stale alarms;
- request time recovery;
- do not sample with knowingly invalid timestamps;
- clear the diagnostic only after a valid TIME_SYNC is applied and persisted.

Do not silently turn a deployed node into an ordinary unpaired node.

Expose the recovery reason in NODE_STATUS or NODE_HELLO when protocol space or
versioning permits.

Power-hold initialization must assert the ON level immediately.

Do not intentionally write the OFF level before asserting hold.

Check the actual hardware polarity and initialise with:

    pinMode(PWR_HOLD_PIN, OUTPUT);
    digitalWrite(PWR_HOLD_PIN, kPwrHoldOnLevel);

before lengthy setup work.

---

# Stage 12 — Reduce unnecessary boot work and NVS wear

Gate the full I2C scan behind:

    #ifndef NODE_I2C_SCAN_ON_BOOT
    #define NODE_I2C_SCAN_ON_BOOT 0
    #endif

Use:

    #if NODE_I2C_SCAN_ON_BOOT
      testI2CBusesMuxAndADS();
    #endif

Do not enable it in the default production environment.

Retain a dedicated bring-up/debug environment that enables it.

Remove unconditional configuration persistence at every boot when nothing
changed.

Review queue persistence frequency and report approximate write volume, but do
not weaken durability merely to reduce writes.

Remove dead code only after confirming it is unused:

- shouldSyncAt() may be removable;
- nextSyncSlotUnix() is used and must remain unless replaced.

Use bounded string copies and validate termination.

Preferences::getString() is valid; changing it to a fixed buffer is optional
cleanup, not a critical bug.

---

# Stage 13 — Production tests

Tests must reuse production code.

Do not write another test that duplicates a simplified callback, dispatcher,
queue, or configuration store.

Extract small production modules where necessary to make real logic testable,
for example:

    message_dispatch.h/.cpp
    node_event_queue.h/.cpp
    config_store.h/.cpp
    espnow_send_manager.h/.cpp
    alarm_manager.h/.cpp

Avoid unnecessary architecture churn, but prefer tested production helpers over
unverifiable monolithic logic.

Required test coverage:

1. Packet dispatch collision.
2. Malformed and unterminated commands.
3. Wrong packet sizes.
4. Wrong sender MAC.
5. Wrong target node ID.
6. Callback returns without I2C/NVS/peer work.
7. Event ordering is preserved.
8. Event queue overflow is counted and safe.
9. Pending TIME_SYNC is applied before power cut.
10. Pending CONFIG_SNAPSHOT is applied before power cut.
11. Delayed unrelated send callback cannot acknowledge a snapshot.
12. Alarm write/read-back success.
13. Alarm corruption detection.
14. No power cut after alarm verification failure.
15. Daily sync mode.
16. Interval sync mode.
17. Config A/B recovery.
18. Queue A/B recovery.
19. Queue mutation rollback.
20. ACK sequence matching.
21. ACK timeout retains the snapshot.
22. Legacy compatibility mode build.
23. Durable ACK mode build.
24. RTC lost-power recovery state.
25. PWR_HOLD starts asserted.

Every test environment must be declared in platformio.ini and compile cleanly.

---

# Stage 14 — Final integration validation

Run all applicable builds, including:

    cd node/firmware

    pio run -e esp32wroom
    pio run -e <dispatch-test>
    pio run -e <callback-production-test>
    pio run -e <alarm-verify-test>
    pio run -e <queue-robustness-test>
    pio run -e <config-store-test>
    pio run -e <daily-sync-test>
    pio run -e <legacy-protocol-build>
    pio run -e <durable-ack-build>

Then perform or provide a bench-test checklist for:

1. Fresh unpaired boot.
2. Explicit pairing.
3. Deployment.
4. First data capture.
5. Interval sync wake.
6. Daily sync wake.
7. CONFIG_SNAPSHOT update.
8. TIME_SYNC during sync window.
9. Mothership unavailable for multiple cycles.
10. Queue retained through power cycles.
11. Queue flush after mothership returns.
12. Alarm I2C failure.
13. RTC lost power.
14. Rapid reboot rescue mode.
15. Direct unpair of only the intended node.
16. SD/mothership durable ACK integration once supported.

---

# Required implementation constraints

Do not:

- force-pop snapshots after three communication failures;
- clear the local queue during ordinary pairing unless this is explicitly
  required and confirmed;
- persist pairing merely from discovery;
- accept broadcast unpair;
- power off after alarm verification fails;
- use packet size alone to identify commands;
- perform NVS, I2C, peer mutation, Wi-Fi reset, or blocking send work in the
  receive callback;
- delete queued data on link-layer success when durable ACK mode is enabled;
- advance configVersion before configuration values are committed;
- rewrite tests as independent copies of production behaviour;
- remove rescue mode, sensor acquisition, or current logging without equivalent
  replacement;
- claim compilation success without showing the command results.

---

# Deliverables

At the end, provide:

1. A concise defect-to-fix mapping.

2. A list of every modified and added file.

3. Full contents of each modified source file, or a clean patch if the repo
   environment supports reliable patch review.

4. The exact PlatformIO commands run and their results.

5. Test results separated into:
   - compiled;
   - executed on host;
   - executed on hardware;
   - still requiring hardware.

6. Any protocol changes and compatibility implications.

7. NVS migration behaviour for existing deployed nodes.

8. Remaining risks that could not be resolved without matching mothership
   changes.

9. A clear statement of whether:
   - legacy mothership mode remains supported;
   - durable SNAPSHOT_ACK mode is implemented;
   - durable ACK mode is enabled by default.

Do not leave placeholder TODOs in release-critical paths.

Implement one stage at a time and preserve a compilable firmware after every
stage.

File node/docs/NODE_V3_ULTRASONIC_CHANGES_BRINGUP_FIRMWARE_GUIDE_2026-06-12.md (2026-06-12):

# Node V3 Ultrasonic Anemometer
## Design Changes, Bring-Up Plan, and Production Firmware Guidance

**Date:** 2026-06-12  
**Board:** Node V3  
**Scope:** 22 V boost, ultrasonic TX path, directional transducer switching, RX analog chain, layout/grounding, bring-up, and final firmware architecture  
**Status:** Schematic/layout revision substantially complete; bench validation pending

---

# 1. Executive Summary

The V3 review began as a focused fix for the MT3608 22 V boost brownout, but the full ultrasonic signal-chain review identified a more fundamental transmit problem:

- The previous Q16 high-side gate network was too slow for carrier-frequency switching.
- `TX_PULSE` did not have a sufficiently strong LOW-state discharge path.
- The firmware drove Q16 at approximately 40 kHz, so Q16 was required to switch every carrier half-cycle.
- The directional `REL_*` controls were clarified as transducer-shunt/damping controls, not simple return-to-ground controls.
- The receive path was hardened with local supply filtering, distributed VREF decoupling, improved sensitive-node placement, better ground referencing, and removal of an unnecessary comparator pull-up.

The revised V3 architecture retains the existing overall topology but corrects the highest-risk faults without introducing a full complementary half-bridge or additional GPIO requirements.

---

# 2. Changes Completed Today

## 2.1 22 V MT3608 Boost Converter

### Inductor

The 22 V boost inductor was changed to:

- **LCSC:** C41406986
- **Value:** 22 µH
- **Saturation current:** approximately 2.5 A
- **Purpose:** replace the previous low-margin inductor that saturated during cold enable and collapsed VSYS.

### Input capacitance

The MT3608 input on `VSYS` now has:

- 100 µF ceramic
- 100 nF ceramic

These are placed locally around the converter input.

### Output capacitance

The output bank was revised from:

- 100 nF + 22 µF + 100 µF

to:

- **100 nF + 22 µF + 22 µF**

Reason:

- reduce cold-start charging energy;
- retain sufficient local storage for the short TX burst;
- reduce the probability of VSYS collapse during converter startup.

The two 22 µF output capacitors must be rated at least 35 V, preferably 50 V. The 100 nF output capacitor should preferably be 50 V.

### U49 enable inverter retained

U49 remains in the design because it provides boot-safe active-low control:

- `GPIO5 / TX_22V_EN_N = HIGH` → U49 output LOW → `EN_22` LOW → boost OFF
- `GPIO5 / TX_22V_EN_N = LOW` → U49 output HIGH → `EN_22` HIGH → boost ON

Changes around U49:

- 1 µF local supply decoupling added
- 100 nF retained
- capacitors moved close to U49 VCC/GND
- `EN_22` test point retained
- no EN hold capacitor added
- no 22 V minimum-load resistor added
- no U49 removal or Schottky replacement implemented

### Layout

The MT3608 layout was reviewed and accepted:

- L1, U22 and D7 are tightly grouped.
- The SW node is compact and limited to:
  - U22 SW pin
  - L1 switching-side pad
  - D7 anode
- No SW test point or long branch is present.
- Feedback divider remains close to the FB pin and outside the SW copper.
- Input/output capacitor return paths were reviewed.
- Ground vias were added or checked around the converter and capacitor grounds.

### Status

- Schematic: approved
- Layout: approved
- Cold-start validation: pending

---

## 2.2 Global 40 kHz TX High-Side Switch

The previous block name "Transmit Burst Enable Switch" was misleading because Q16 switches at the actual carrier frequency. It should be documented as:

> **40 kHz High-Side TX Pulse Switch**

### Confirmed firmware behaviour

`TX_BURST_PWM` on GPIO25 is the actual carrier:

- bit-banged HIGH/LOW
- approximately 12 µs per half-cycle
- nominal 41.7 kHz before software overhead
- 12 cycles in the current bring-up firmware
- approximately 300 µs burst duration

Therefore Q16 must turn ON and OFF during every carrier cycle.

### Q16 gate-drive correction

Previous problem:

- R112 = 100 kΩ was the only Q16 turn-off path.
- The resulting gate time constant was tens of microseconds.
- This was too slow for a 12 µs LOW interval.

Applied changes:

- **R112 changed from 100 kΩ to 4.7 kΩ**
- **R5 = 1 kΩ added between `HS_GATE` and Q21 drain**
- D10 = BZT52C15 retained as Q16 gate-source protection
- Q21 = 2N7002 retained
- R113 = 33 Ω retained
- R114 = 100 kΩ retained

Expected operation:

- Q21 OFF:
  - R112 pulls `HS_GATE` toward `22V_SYS`
  - Q16 turns OFF
- Q21 ON:
  - R5 limits current
  - D10 limits negative Q16 VGS
  - Q16 turns ON

### Strong TX_PULSE LOW state

The old 220 kΩ resistor was only a slow bleed and could not discharge the TX node during a 12 µs LOW half-cycle.

Applied change:

- **R6 = 1 kΩ from `TX_PULSE` to GND**
- Existing R182 = 220 kΩ retained as an off-state bleed
- R6 should use at least a 1206 footprint and suitable pulse rating

Reason:

- gives the single-ended TX architecture a deterministic LOW without:
  - another GPIO;
  - complementary PWM;
  - dead-time circuitry;
  - shoot-through risk.

Expected initial performance with an estimated 2.5 nF TX capacitance:

- RC ≈ 2.5 µs
- `TX_PULSE` should fall close to ground within a 12 µs LOW interval

### Local 22 V capacitors

- 100 nF verified for suitable voltage
- 1 µF upgraded to 0805 and verified for suitable voltage

### Status

- Q16 gate network: approved
- passive TX pull-down: approved
- PCB placement and ground return: approved in principle
- oscilloscope validation: pending

---

## 2.3 Directional Transducer Driver Channels

The North channel was reviewed in detail and the same changes were replicated across East, South and West.

### Correct functional interpretation

The directional controls are:

- `DRV_x`: connects `TX_PULSE` to the selected transducer terminal through the directional P-channel MOSFET
- `REL_x`: turns on a shunt MOSFET across the transducer terminals for damping

`REL_x` is therefore better understood as:

- `DAMP_x`
- `SHUNT_x`

The physical net names may remain `REL_*`, but the firmware and documentation must describe their true purpose.

### Required directional truth table

| DRV_x | REL_x | State |
|---:|---:|---|
| LOW | LOW | Idle / receive |
| HIGH | LOW | Transmit |
| LOW | HIGH | Damping / transducer short |
| HIGH | HIGH | Forbidden while TX_PULSE is active |

### High-side directional gate-network changes

For each directional P-channel MOSFET:

- source pull-up changed from **10 kΩ to 1 kΩ**
- new **1 kΩ resistor** added between the P-MOS gate node and the 2N7002 drain
- 15 V gate-source zener retained
- GPIO-side 100 Ω gate resistor retained
- 100 kΩ gate pulldown retained

For North:

- R116 changed to 1 kΩ
- R7 added as 1 kΩ
- Q17 retained
- Q22 retained
- D11 retained

Equivalent changes were applied to East, South and West.

Reason:

- inactive P-MOS gates must track the fast `TX_PULSE` source to stay OFF;
- selected P-MOS gates need a controlled and predictable ON drive;
- the zener should act as protection rather than an uncontrolled current path.

### Shunt/damping MOSFETs

Retained:

- 100 Ω gate resistor
- 100 kΩ pulldown
- CJ2310 shunt MOSFET
- hardware-safe OFF state at boot

### R121-style transducer ground resistor

The 1 kΩ resistor from one transducer terminal to GND was retained.

This is a tuning component affecting:

- transmit amplitude;
- receive sensitivity;
- electrical damping;
- ring-down duration;
- transducer loading.

Do not change it until acoustic bring-up data is available.

### Status

- North topology: signed off
- East/South/West replication: accepted
- visual consistency/ERC check still required
- acoustic truth table validation pending

---

## 2.4 Comparator Supply and Output

### Local comparator supply filter

Added:

- 4.7 Ω series resistor from `3V3_SYS`
- 100 nF to GND after the resistor
- 1 µF to GND after the resistor

The capacitors are placed on the comparator side of the resistor.

Recommended local net name:

- `3V3_COMP`

### Local VREF capacitor

Added:

- 100 nF from VREF to GND at the comparator reference input

### Comparator pull-up removed

U44 is an MCP6561-family push-pull comparator.

Therefore:

- **R110 = 10 kΩ pull-up on COMP_RAW was removed**

Reason:

- push-pull output does not need an external pull-up;
- the pull-up unnecessarily coupled raw `3V3_SYS` into `COMP_RAW`;
- it created an unnecessary load when COMP_RAW was LOW.

### Hysteresis

No change was made to current hysteresis:

- R109 = 1 MΩ retained
- R179 retained unchanged
- no extra footprint added

Decision:

- first validate the improved TX waveform, supply filtering and VREF stability;
- tune hysteresis only if COMP_RAW still chatters.

### Digital blanking

Retained:

- U50 inverter:
  - `RX_WINDOW_EN = NOT RX_EN_N`
- U51 AND gate:
  - `TOF_EDGE = COMP_RAW AND RX_WINDOW_EN`
- 100 nF local decoupling for U50 and U51
- R178 = 0 Ω gated output path

### Status

- comparator block signed off
- hysteresis tuning pending only if required by measurements

---

## 2.5 TLV9062 RX Amplifier Supply

Added local supply filtering:

- 4.7 Ω series resistor from `3V3_SYS`
- 100 nF local capacitor
- 1 µF local capacitor

Both capacitors are on the TLV9062 side of the resistor and close to the shared VCC/GND pins of the dual op-amp.

Recommended local net name:

- `3V3_RXAMP`

No additional capacitance was added to signal nodes such as:

- `ST1_IN`
- `ST1_OUT`
- `ST2_IN`
- `RX_AMP`

This avoids unintentionally changing filter gain, phase or timing.

---

## 2.6 74HC4052 RX Mux Supply

Added:

- 4.7 Ω series resistor between `3V3_SYS` and U42 VCC
- existing 100 nF retained on the mux side of the resistor

Recommended local net name:

- `3V3_MUX`

The RX clamp upper rails remain connected to normal `3V3_SYS`, not the filtered mux/op-amp/comparator islands. This avoids dumping transient clamp current into a quiet local analog supply.

---

## 2.7 VREF Network

### Main VREF source

Revised to:

- 3V3_SYS
- 220 Ω series feed resistor
- 47 kΩ / 47 kΩ divider
- VREF approximately 1.65 V

Main VREF decoupling now includes:

- 100 nF
- 1 µF
- 4.7 µF

### Distributed local VREF decoupling

Added:

- 100 nF at comparator VREF input
- 100 nF at the first amplifier VREF bias area
- 100 nF at the second amplifier VREF bias area

Reason:

- the VREF route is relatively long;
- local capacitors reduce reference movement and TX-correlated pickup at each consumer.

### Firmware implication

Because total VREF capacitance is now several microfarads, allow VREF to settle before the first acoustic measurement.

Initial conservative recommendation:

- 500 ms after board power-up before the first ultrasonic measurement
- later reduce based on measured VREF settling time

---

## 2.8 RX Protection

The RX protection topology was retained:

### Hot side

- `RX_HOT`
- R100 = 2.2 kΩ series resistor
- BAV99 clamp to GND and `3V3_SYS`
- C103 = 220 pF to GND
- R174 = 1 MΩ to VREF
- C102 = 1 nF coupling capacitor to `ST1_IN`

### Cold side

- `RX_COLD`
- R152 = 2.2 kΩ series resistor
- BAV99 clamp to GND and `3V3_SYS`
- R107 = 100 kΩ to VREF
- C109 = 1 nF in parallel with R107

The series resistors remain before the clamps.

No extra comparator-input clamp or additional signal-node capacitance was added.

---

## 2.9 RX Layout and Ground Referencing

### C102 moved

C102 was moved next to the TLV9062 first-stage input.

Result:

- `ST1_IN` is now extremely short
- no long high-impedance trace remains after the coupling capacitor
- the longer route is now `RX_IN`, which is the better trade-off

### RX_IN routing

`RX_IN` runs primarily on the bottom layer.

The 4-layer stack remains:

- L1 Top signal
- L2 GND
- L3 Power
- L4 Bottom signal

The 5 V pour beneath the long RX_IN route was moved and replaced with a local GND corridor on L3.

Added/verified:

- GND beneath most/all of the bottom RX_IN trace
- GND stitching beside RX_IN layer-transition vias
- local GND corridor stitched to the main ground plane
- no floating GND island
- 5 V pour continuity retained

This removed the immediate need to move to a 6-layer board.

### RX_AMP and COMP_RAW

Both routes were reviewed and accepted:

- `RX_AMP` remains short and local between TLV9062 and comparator
- `COMP_RAW` remains short and local between U44 and U51
- neither loops back beside the comparator inputs or VREF
- test points are acceptable because both are actively driven, low-impedance nodes

### TX/RX zoning

Reviewed and accepted:

- 22V_SYS remains in the TX area
- TX_PULSE remains in the centre/upper TX area
- RX analog circuitry remains lower-right
- no major TX route crosses the RX front end
- no major TX_PULSE reroute was required

---

## 2.10 Ground Via Additions

Ground vias were added or reviewed at these critical locations:

- TLV9062 100 nF and 1 µF capacitor grounds
- comparator 100 nF and 1 µF capacitor grounds
- mux 100 nF ground
- U49 100 nF and 1 µF grounds
- U50/U51 decoupling grounds
- TC4427 decoupling ground
- main and local VREF capacitor grounds
- D8/D9 clamp ground returns
- both RX_IN signal layer transitions
- MT3608 GND
- MT3608 input capacitor grounds
- MT3608 output capacitor grounds
- Q16 TX_PULSE 1 kΩ pulldown ground
- Q21 and directional gate-driver source grounds
- local GND corridor stitching

---

# 3. Deliberate Non-Changes

The following were considered but intentionally not implemented:

- U49 removal
- Schottky-isolated EN_22 replacement
- EN_22 hold capacitor
- 22V_SYS minimum-load resistor
- 470 µF–1000 µF optional VSYS bulk capacitor
- L7 / 5 V boost inductor replacement
- full shared `3V3_A` bus
- new comparator hysteresis footprint
- active low-side TX MOSFET / full half-bridge
- complementary PWM hardware
- analog RX mute switch
- major TX_PULSE reroute
- 6-layer board conversion

These may be revisited only if bring-up measurements justify them.

---

# 4. Mandatory Schematic and Layout Checks Before Ordering

## Schematic/ERC

- Confirm GPIO-side boost net is consistently named `TX_22V_EN_N`.
- Confirm MT3608-side enable net is `EN_22`.
- Confirm U49 is not bypassed.
- Confirm Q16 source/drain/gate mapping.
- Confirm all four directional P-MOSFET source/drain/gate mappings.
- Confirm D10/D11-style zener cathodes connect to their P-MOS source nodes.
- Confirm BAV99 symbol-to-footprint mappings.
- Confirm R110 is removed from BOM/netlist.
- Confirm R6 = 1 kΩ TX_PULSE pulldown is populated.
- Confirm all four directional channels use the same revised resistor values.
- Confirm `DRV_* HIGH + REL_* HIGH` is documented as forbidden during TX.
- Confirm C84/U1/U2 final output capacitor values are two 22 µF capacitors, not 100 µF.
- Confirm all 22 V capacitors have suitable voltage ratings.

## PCB/DRC

- Repour all copper zones.
- Run DRC after every final route change.
- Confirm no isolated GND or power islands.
- Confirm no narrow 5 V bottleneck after moving the pour.
- Confirm RX_IN remains above the new L3 GND corridor.
- Confirm GND vias are close to RX_IN layer transitions.
- Confirm ST1_IN remains very short and without a test point.
- Confirm the MT3608 SW node remains compact.
- Confirm no sensitive net is routed beneath the MT3608 SW node.
- Confirm feedback does not run near SW/L1.
- Confirm R6 ground return is local and does not pass through the RX analog ground area.
- Confirm all new 0402/0603/0805/1206 footprints match JLC assembly capability and BOM parts.

---

# 5. Detailed Ultrasonic Bring-Up Plan

## Phase 0 — Equipment and Safety

Recommended equipment:

- current-limited bench supply or known-good Li-ion battery
- two- or four-channel oscilloscope
- 10× probes rated above 30 V
- DMM
- optional differential probe
- reference 40 kHz ultrasonic transducer or microphone
- physical acoustic blocker
- reference anemometer for final calibration

Scope safety:

- connect all ordinary probe ground clips only to board GND
- never connect a ground clip to `22V_SYS`
- never connect a ground clip to either transducer terminal
- use two probes plus math for:
  - `HS_GATE - 22V_SYS`
  - `TD_x_A - TD_x_B`

Initial scope settings for carrier work:

- 5–10 µs/div
- 5 or 10 V/div for 22 V nodes
- 2 V/div for logic nodes
- trigger on `PWM_5V`

---

## Phase 1 — Unpowered Inspection

With power disconnected:

1. Check resistance from:
   - VSYS to GND
   - 3V3_SYS to GND
   - 5V_SYS to GND
   - 22V_SYS to GND
   - TX_PULSE to GND
2. Confirm TX_PULSE reflects approximately the new 1 kΩ pulldown.
3. Check no short exists across Q16 source/drain.
4. Check each directional channel:
   - DRV gate pulldown present
   - REL gate pulldown present
   - no unintended short across transducer terminals
5. Check all new filter resistors have expected continuity.
6. Check filtered local rails are not accidentally labelled or shorted directly to `3V3_SYS`.

---

## Phase 2 — Low-Voltage System Only

Keep the 22 V boost disabled.

Validate:

- VSYS
- 3V3_SYS
- 5V_SYS
- `3V3_COMP`
- `3V3_RXAMP`
- `3V3_MUX`
- VREF

Expected:

- 3V3 local filtered nodes close to 3.3 V
- VREF approximately 1.65 V
- boost OFF at boot
- `EN_22` LOW
- `22V_SYS` near 0 V
- `TX_PULSE` near 0 V
- all DRV/REL outputs LOW
- `RX_EN_N` HIGH
- `TOF_EDGE` blocked

Measure VREF startup settling and use this result to refine the initial firmware wait.

---

## Phase 3 — 22 V Cold-Start Validation

Test with:

- battery or bench supply near 4.0–4.1 V
- ESP32 fully running
- no TX burst initially

Probe:

- VSYS
- 3V3_SYS
- EN_22
- 22V_SYS

Sequence:

1. Boot with boost disabled.
2. Enable boost once from cold.
3. Hold enabled for at least 100 ms.
4. Disable.
5. Repeat from a fully discharged output.

Pass criteria:

- no `POWERON_RESET`
- no ESP32 brownout
- VSYS does not collapse
- 3V3_SYS remains stable
- EN_22 remains steady
- 22V_SYS reaches approximately 22 V
- converter does not hiccup
- MT3608 and L1 do not heat rapidly

Also test at:

- 4.2 V battery
- approximately 3.7 V
- low usable battery voltage

If cold start still fails:

1. scope inductor/SW behaviour;
2. test with one output 22 µF removed;
3. reconsider inductor current margin;
4. only then reconsider extra VSYS bulk capacitance or enable strategy.

---

## Phase 4 — Carrier Chain Without Directional Load

Generate a short carrier burst with all directional channels disabled.

Probe:

- GPIO25 / TX_BURST_PWM
- PWM_5V
- HS_GATE
- TX_PULSE
- 22V_SYS

Expected:

### GPIO25

- stable hardware-generated carrier once production firmware is implemented
- during temporary bring-up, bit-banged waveform may show timing variation

### PWM_5V

- clean 0–5 V square wave
- no excessive edge distortion

### HS_GATE

- OFF state near 22V_SYS
- ON state approximately 7–11 V depending on clamp operation
- returns to OFF before the next carrier edge
- no slow accumulation across cycles

### TX_PULSE

- HIGH preferably above 20 V
- LOW preferably below 1–2 V before the next rising edge
- no DC accumulation over the burst
- no severe ringing or overshoot

### 22V_SYS

- stable during the complete burst
- no large collapse or oscillation

Fail conditions:

- TX_PULSE rises once and remains high
- TX_PULSE LOW remains several volts high
- HS_GATE does not return to the source level
- 22V_SYS collapses during burst
- Q16/Q21/R6 heat unexpectedly

---

## Phase 5 — One Directional Channel at a Time

Start with North.

Required transmit state:

- `DRV_N = HIGH`
- `REL_N = LOW`
- all other DRV/REL outputs LOW

Probe:

- TX_PULSE
- `DRV_GATE_N`
- `TD_N_A`
- `TD_N_B`
- differential transducer voltage using scope math

Expected:

- Q17 gate approximately 11 V below/relative to source conditions needed for ON
- TD_N_A follows TX_PULSE
- TD_N_B remains referenced through the existing 1 kΩ network
- clear 40 kHz differential waveform across the transducer

Repeat with North disabled while another channel is active.

Inactive-channel pass criterion:

- only small capacitive spikes
- no near-full-amplitude pulse on inactive transducer terminals

Repeat for East, South and West.

---

## Phase 6 — Damping State

After a transmit burst:

1. set `DRV_x = LOW`
2. allow a short non-overlap delay
3. set `REL_x = HIGH` for a configurable damping interval
4. set `REL_x = LOW`
5. enter idle/receive state

Never allow:

- `DRV_x = HIGH`
- `REL_x = HIGH`
- while TX_PULSE is active

Initial damping interval to test:

- 10–50 µs

Tune using transducer ring-down measurements.

Compare:

- no damping
- 10 µs
- 20 µs
- 50 µs

Select the shortest interval that reduces ring-down without suppressing the desired receive event.

---

## Phase 7 — RX Baseline Validation

Keep TX disabled.

Test:

- RX mux disabled
- RX mux enabled
- each mux direction
- comparator raw output
- gated TOF output

Probe:

- VREF
- RX_IN
- ST1_OUT
- RX_AMP
- COMP_RAW
- TOF_EDGE

Pass targets:

- VREF stable
- RX_IN settles toward VREF when disconnected
- baseline COMP_RAW edges near zero in the expected acoustic window
- TOF_EDGE zero when RX is disabled
- no TX-correlated event because TX is inactive

Do not adjust hysteresis yet unless the improved hardware still produces comparator chatter.

---

## Phase 8 — Electrical Coupling Test

Disconnect or acoustically/electrically isolate the RX transducer.

Transmit normally.

Measure:

- COMP_RAW event count
- TOF_EDGE detection rate
- first-edge time distribution

Target:

- detection rate should drop substantially
- desirable initial target: less than 10% false detection in the expected TOF gate
- no stable "arrival" time should remain when the RX transducer is disconnected

If detection remains high:

- inspect TX_PULSE edge ringing
- inspect VREF movement
- inspect RX_IN pickup
- compare COMP_RAW and TOF_EDGE
- test lower burst cycles
- test longer/shorter damping
- only then tune hysteresis

---

## Phase 9 — Open vs Blocked Acoustic Test

With the transducers installed:

1. record at least 50–100 open-path shots
2. physically block the acoustic path
3. record the same number of blocked-path shots

Compare:

- detection rate
- median first valid TOF
- jitter
- edge count
- signal/noise separation

Pass target:

- blocked and open distributions clearly separate
- blocked detection rate should fall strongly
- median separation should exceed normal open-path jitter by a large margin

---

## Phase 10 — Reciprocal Direction Test

For one axis:

- measure N→S
- measure S→N

At still air:

- corrected reciprocal TOFs should be nearly equal
- the difference should be stable around a calibration offset

With directed airflow:

- reciprocal TOF difference should change sign when direction reverses
- sign should be stable across repeated shots
- open-path median difference should exceed jitter

Acceptance target:

- direction sign correct in at least 90–95% of valid reciprocal pairs
- no persistent same-time detection across every direction

---

## Phase 11 — Wind Calibration

Known constants:

- path length: 146.70 mm
- nominal still-air TOF: approximately 427 µs
- projection factor: 0.5344

For reciprocal path times:

- `t_down = L / (c + v_path)`
- `t_up = L / (c - v_path)`

Path-axis velocity:

`v_path = (L / 2) × (1 / t_down - 1 / t_up)`

Projected wind-axis velocity:

`v_axis = v_path / 0.5344`

Use seconds and metres in calculations.

Calibration requirements:

- per-direction electronic timing offsets
- per-axis zero-wind offset
- path-length calibration
- temperature compensation
- outlier rejection
- reference-anemometer comparison

---

# 6. Production Firmware Design

## 6.1 Replace bit-banged PWM

Do not use `digitalWrite()` and `delayMicroseconds()` in production.

Recommended architecture:

### TX burst

Use **ESP32 RMT TX** for:

- exact HIGH/LOW durations
- exact cycle count
- deterministic final LOW state
- configurable carrier frequency
- minimal CPU jitter

Alternative:

- MCPWM or LEDC, but RMT is especially convenient for a finite burst with exact pulse count.

Initial carrier parameters:

- start around 40 kHz
- sweep approximately 38–42 kHz during bring-up
- 50% duty initially
- start with 6 cycles
- tune between 4 and 10 cycles based on acoustic SNR and ring-down

The current 12-cycle burst is long relative to the 146.7 mm acoustic path and current blanking strategy.

---

## 6.2 Use Hardware Edge Capture

Do not use `micros()` in a GPIO ISR for final wind measurement.

Reason:

- 1 m/s produces only about a 1.33 µs reciprocal split
- useful accuracy needs sub-microsecond timing
- ISR and software timestamp jitter are too large

Recommended:

- MCPWM capture input on TOF_EDGE
- or RMT RX configured at a sufficiently high clock resolution

Target capture resolution:

- 100 ns or better preferred
- 250 ns may be usable
- 1 µs is not sufficient for high-quality wind measurements

Capture multiple edges during bring-up, not only the first edge. This helps diagnose comparator chatter and select a robust event.

---

## 6.3 Correct the TX/RX Timing Reference

Current firmware waits approximately:

- 300 µs burst
- 320 µs blanking after burst
- 20 µs mux settle
- 20 µs guard

This opens the receive path approximately 640 µs after the first TX edge.

The nominal acoustic arrival begins around 427 µs after the first transmitted edge, so the present sequence can miss the first acoustic arrival and capture later ring-down or noise.

Production timing must reference a defined TX edge.

Recommended initial approach:

1. record the timestamp of the first TX rising edge;
2. generate 4–8 cycles;
3. keep RX blocked during the electrical burst;
4. optionally apply transmitter damping;
5. open RX sufficiently before the expected arrival;
6. accept TOF only inside an absolute gate referenced to the first TX edge.

Initial expected acoustic gate:

- approximately 350–550 µs from the first TX edge

Refine after measuring:

- temperature range
- filter group delay
- comparator delay
- real transducer ring-up
- mechanical path length

Do not define `MIN_VALID_TOF_US` relative only to `listenStartUs`. Use the hardware TX timestamp as the common time origin.

---

## 6.4 Recommended Measurement State Machine

### `SAFE_IDLE`

- TX_BURST_PWM LOW
- TX_22V_EN_N HIGH
- all DRV LOW
- all REL LOW
- RX_EN_N HIGH
- capture disabled

### `SELECT_PATH`

- set RX mux direction while RX remains disabled
- set selected TX DRV LOW/REL LOW
- clear all other channels
- wait for control settling

### `BOOST_PRECHARGE`

- enable 22 V boost
- wait until stable
- initially use 20–50 ms
- later reduce using measurements or optional rail validation

### `ARM_TIMING`

- clear hardware capture
- record/prepare TX time origin
- keep RX blocked

### `TRANSMIT`

- set selected `DRV_x = HIGH`
- keep selected `REL_x = LOW`
- emit exact RMT burst
- finish carrier LOW

### `DAMP`

- set `DRV_x = LOW`
- wait short non-overlap interval
- set `REL_x = HIGH`
- hold for configurable damping interval
- set `REL_x = LOW`

### `RX_PREPARE`

- wait until configured receive-open time
- set RX_EN_N LOW
- allow mux/analog settle
- arm hardware capture before expected arrival

### `CAPTURE`

- accept edges only inside expected absolute TOF window
- capture multiple edges for diagnostics
- classify first valid acoustic event
- stop at timeout

### `CLEANUP`

- RX_EN_N HIGH
- all DRV LOW
- all REL LOW
- TX_BURST_PWM LOW
- disable boost
- save raw measurement and diagnostics

---

## 6.5 Firmware Safety Rules

Enforce these invariants:

- boost must not enable until all DRV/REL outputs are configured
- TX_BURST_PWM must always idle LOW
- only one DRV channel may be HIGH
- `DRV_x HIGH + REL_x HIGH` is forbidden while TX_PULSE is active
- all DRV and REL pins return LOW after every shot
- RX remains disabled during the electrical TX burst
- boost-only test firmware with inverted GPIO5 logic must not run on a board with U49 fitted
- production firmware must not use legacy V1 RX polarity
- any timeout/error must call a single fail-safe cleanup function

Suggested assertion:

```cpp
bool txStateSafe() {
  return activeDrvCount() <= 1 &&
         !(selectedDrvHigh() && selectedRelHigh() && txCarrierActive());
}
```

---

## 6.6 Configurable Bring-Up Parameters

Expose these through a debug menu or serial command interface:

- carrier frequency
- half-period
- burst cycles
- boost precharge duration
- damping duration
- RX enable time
- RX settle time
- expected TOF window start/end
- comparator edge selection
- direction selection
- DRV/REL state
- inter-shot delay
- number of warm-up shots
- number of scored shots

Log all settings with each test result.

---

## 6.7 Required Raw Data Per Shot

Store:

- TX direction
- RX direction
- carrier frequency
- cycle count
- TX first-edge timestamp
- TX final-edge timestamp
- RX enable timestamp
- all captured TOF edge timestamps within the gate
- selected edge index
- edge count
- timeout status
- 22V_SYS if available
- battery voltage
- temperature
- path blocked/open test flag
- firmware version
- PCB revision

Do not store only the final wind speed during bring-up. Preserve raw TOF data.

---

## 6.8 Filtering and Outlier Handling

Use reciprocal shot pairs.

Recommended initial processing:

1. reject shots with no edge in the expected gate;
2. reject shots with abnormal edge count;
3. reject TOFs outside the physical path window;
4. calculate median of repeated shots;
5. use MAD or robust percentile limits for outliers;
6. pair opposite directions close in time;
7. calculate reciprocal velocity after per-direction offset correction.

Do not average feedthrough-dominated detections into a wind result.

---

## 6.9 Calibration Data

Store in non-volatile configuration:

- path length per axis
- projection factor
- carrier frequency per transducer pair if needed
- zero-wind TOF offset per direction
- comparator/filter timing offset
- temperature correction coefficients
- minimum signal-quality criteria
- acceptable edge-count range
- per-channel damping duration

---

# 7. Bring-Up Acceptance Criteria

The system is not acoustically validated until all of these are met:

## Electrical

- no cold-start ESP32 reset
- 22V_SYS stable
- Q16 gate fully returns each cycle
- TX_PULSE >20 V HIGH
- TX_PULSE <1–2 V LOW before next rising edge
- inactive channels show only minor capacitive coupling
- no sustained excessive heating

## RX baseline

- TOF_EDGE = 0 when RX disabled
- baseline edges near zero inside expected TOF gate
- VREF shows no significant TX-correlated movement
- local filtered rails remain stable

## Acoustic discrimination

- disconnected RX transducer dramatically reduces detection
- blocked path clearly differs from open path
- reciprocal direction deltas are stable in sign
- reversed airflow reverses delta sign
- open-path median separation exceeds jitter
- detections occur in the physically plausible arrival window

## Timing

- first valid acoustic arrival is captured near expected 410–450 µs range at normal temperatures
- timing is referenced to hardware TX edge
- capture resolution is sub-microsecond

---

# 8. Immediate Next Actions

1. Complete final ERC/DRC.
2. Verify all four directional driver blocks match.
3. Verify BOM values and capacitor voltage ratings.
4. Create a formal V3 bring-up firmware branch.
5. Implement safe-state initialization.
6. Implement RMT TX burst.
7. Implement hardware TOF capture.
8. Implement corrected DRV/REL truth table.
9. Implement absolute acoustic timing gate.
10. Bench-test:
    - 22 V cold start
    - Q16 gate
    - TX_PULSE
    - one directional channel
    - RX baseline
    - disconnected receiver
    - open/blocked path
    - reciprocal directions

---

# 9. Key Firmware Corrections to Existing Bring-Up Code

The existing authoritative bring-up code must eventually be revised because:

- bit-banged PWM is not sufficiently deterministic;
- the present 320 µs post-burst blanking is too late for the first acoustic arrival with a 12-cycle burst;
- the current test sweep allows `DRV_x = HIGH` and `REL_x = HIGH`, which is an invalid TX state;
- TOF is timestamped relative to the receive/listen sequence rather than a precise hardware TX edge;
- production ultrasonic code is currently only a stub;
- the platformio.ini corruption around `PIN_DRV_W` / `PIN_REL_N` must be fixed;
- the boost-only inverted-GPIO5 test must remain isolated from normal U49-equipped firmware.

---

# 10. Final Design Position

The recommended V3 direction is now:

- keep the existing single-ended TX architecture;
- keep GPIO25 as the only carrier control;
- use the corrected Q16 gate network;
- use the passive 1 kΩ TX_PULSE pulldown;
- retain directional P-MOS switching;
- use REL signals only as post-TX damping controls;
- retain hardware output blanking;
- retain local analog supply islands;
- retain distributed VREF decoupling;
- keep the revised RX_IN/ST1_IN layout;
- use hardware-generated TX timing and hardware capture in production firmware;
- validate acoustics before further analog/hysteresis redesign.

This limits PCB risk while addressing the most likely causes of V1/V2 feedthrough-dominated behaviour.

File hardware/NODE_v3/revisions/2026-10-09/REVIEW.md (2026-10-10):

# Node v3 ultrasonic and 22 V removal plan — 2026-10-09 baseline

- **Review date:** 2026-10-09
- **EasyEDA source:** `NODE_ProPrj_NODE_V3_2026-10-09.epro2`
- **Release directory:** `hardware/NODE_v3/revisions/2026-10-09`
- **Baseline status:** Reported field-proven and working

**Recommendation for this pass:** preserve this release unchanged as the
known-good baseline. Make the deletions below in a new EasyEDA project copy,
then submit a new source/BOM/CPL/Gerber set for a removal-only comparison.

The scope is deliberately limited to:

1. the ultrasonic transmit chain;
2. the ultrasonic receive chain;
3. the 22 V converter and its enable circuit; and
4. the two 22 V sensor-supply branches that become unusable when the 22 V rail
   is removed.

This review does **not** assess or redesign the circuits that remain. In
particular, it does not change the 3.3 V or 5 V regulators, charger, power
latch, RTC, USB interface, ADC signal inputs, I2C expansion, or auxiliary reed
wind input.

## Baseline integrity

The four supplied files were copied byte-for-byte into this release directory.

| Check | Result |
|---|---|
| EasyEDA source archive | Pass; ZIP structure tests successfully |
| Gerber archive | Pass; all 17 members test successfully |
| Copper/drill set | Four copper layers, top/bottom mask, top paste, top/bottom silk, outline, PTH, NPTH, and via drill data present |
| BOM | 103 groups and 331 unique references |
| Pick-and-place | 331 unique references; exact reference-set match to the BOM |
| Source PCB | 331 components and 331 unique IDs; exact unique-ID match to the BOM |
| Assembly side | All 331 placements are top-side |

| File | SHA-256 |
|---|---|
| `NODE_BOM_Board1_PCB1_2026-10-09.csv` | `c7339d9492b1f3b86b2f0fbfe956de930a6b1f6533fb00ff043c2a09640fde88` |
| `NODE_PickAndPlace_PCB1_2026_10_09.csv` | `55df2a648c2dfb119f9d7197b62a48c9e4a2f1668d9c5c9b9b4063d7c366b61e` |
| `NODE_ProPrj_NODE_V3_2026-10-09.epro2` | `1713a1c492eb72fe7e650674b6c31dcb561eb1002ed45b65786aa43dfb0bef30` |
| `NODE_Gerber_PCB1_2026-10-09.zip` | `4f04bba4c7f9eb9765b55f9f3b317c3fa599cc47bda87dca39257a58e5a50767` |

## Removal boundary

The baseline contains 331 placed references. The exact removal set below has
159 references, leaving an expected 172 references in both the BOM and
pick-and-place export.

| Block | Remove | Expected references removed |
|---|---|---:|
| 22 V converter and enable | Entire 22 V block on `POWER _REG:` | 20 |
| Ultrasonic TX | Entire `ULTRASONIC_V2_TX` circuit plus the MCU-side `TX_PWM` test point | 68 |
| Ultrasonic RX | Entire `ULTRASONIC_V2_RX` circuit | 53 |
| 22 V sensor branches | Both 22 V high-side branches on `ADC`; retain their 5 V alternatives | 18 |
| **Total** |  | **159** |

Do not run annotation or renumber the retained components during this work.
Stable references make the removal-only comparison auditable.

## Instructions in EasyEDA Pro

### 1. Create the working revision

1. Import/open `NODE_ProPrj_NODE_V3_2026-10-09.epro2`.
2. Immediately save a copy under a new project/revision name.
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

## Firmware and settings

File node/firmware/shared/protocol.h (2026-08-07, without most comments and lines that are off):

#pragma once
#include <Arduino.h>
typedef struct sensor_data_message {
    char nodeId[16];            // e.g., "TEMP_001"
    char sensorType[16];        // e.g., "SOIL_TEMP", "AIR_TEMP"
    char sensorLabel[24];       // e.g., "SOIL1_TEMP", "AUX1_INPUT"
    uint16_t sensorId;          // stable channel id for downstream processing
    float value;                // reading
    unsigned long nodeTimestamp;// node-side timestamp (unix or millis)
    uint16_t qualityFlags;      // reserved for sensor/time/queue quality bits
} sensor_data_message_t;
typedef struct discovery_message {
    char nodeId[16];
    char nodeType[16];          // "temperature", "humidity", etc.
    char command[20];           // "DISCOVER_REQUEST"
    unsigned long timestamp;
} discovery_message_t;
typedef struct discovery_response {
    char command[20];           // "DISCOVER_RESPONSE" or "DISCOVERY_SCAN"
    char mothership_id[16];
    bool acknowledged;
} discovery_response_t;
typedef struct pairing_request {
    char command[20];           // "PAIRING_REQUEST"
    char nodeId[16];
} pairing_request_t;
typedef struct pairing_response {
    char command[20];           // "PAIRING_RESPONSE"
    char nodeId[16];
    bool isPaired;
    char mothership_id[16];
} pairing_response_t;
typedef struct pairing_command {
    char command[20];           // "PAIR_NODE"
    char nodeId[16];
    char mothership_id[16];
} pairing_command_t;
typedef struct deployment_command {
    char command[20];           // "DEPLOY_NODE"
    char nodeId[16];
    unsigned long year, month, day, hour, minute, second;
    uint16_t configVersion;     // desired config snapshot version at deploy time
    uint8_t wakeIntervalMin;    // desired wake interval to apply immediately
    uint16_t syncIntervalMin;   // desired sync interval to apply immediately
    uint32_t syncPhaseUnix;     // desired sync phase anchor to apply immediately
    char mothership_id[16];
    uint16_t sensorMask;       // operator-selected sensors (SNAP_PRESENT_* +
    uint16_t deploymentEpoch;
} deployment_command_t;
typedef struct deployment_ack_message {
    char command[20];           // "DEPLOY_ACK"
    char nodeId[16];
    uint8_t deployed;           // 1=deployed applied, 0=failed
    uint32_t rtcUnix;           // node RTC unix at ACK time
} deployment_ack_message_t;
typedef struct time_sync_request {
    char nodeId[16];
    char command[16];           // "REQUEST_TIME"
    unsigned long requestTime;
} time_sync_request_t;
typedef struct time_sync_response {
    char command[16];           // "TIME_SYNC"
    unsigned long year, month, day, hour, minute, second;
    char mothership_id[16];
} time_sync_response_t;
typedef struct unpair_command {
    char command[16];           // "UNPAIR_NODE"
    char nodeId[16];            // target node ID; prevents broadcast unpairing every node
    char mothership_id[16];
} unpair_command_t;
typedef struct schedule_command_message {
    char command[16];           // "SET_SCHEDULE"
    int  intervalMinutes;       // 1,5,10,20,30,60
    char mothership_id[16];
} schedule_command_message_t;
typedef struct sync_schedule_command_message {
    char command[20];           // "SET_SYNC_SCHED"
    unsigned long syncIntervalMinutes;
    unsigned long phaseUnix;    // alignment anchor (unix seconds)
    char mothership_id[16];
} sync_schedule_command_message_t;
typedef struct node_config_message {
    char     command[16];       // "NODE_CONFIG"
    char     nodeId[16];        // target node (broadcast-safe; node matches its own NODE_ID)
    char     mothership_id[16];
    uint16_t configVersion;     // monotonic desired version
    uint8_t  targetState;       // 0=UNPAIRED, 1=PAIRED, 2=DEPLOYED
    uint8_t  wakeIntervalMin;   // 1,5,10,20,30,60
    uint16_t syncIntervalMin;   // sync cadence (minutes)
    uint16_t sensorMask;        // expected/configured sensors — SNAP_PRESENT_* bits
    uint32_t syncPhaseUnix;     // sync anchor (unix seconds)
} node_config_message_t;
typedef struct node_hello_message {
    char command[16];       // "NODE_HELLO"
    char nodeId[16];
    char nodeType[16];
    uint16_t configVersion; // config version node currently has applied (0 = none)
    uint8_t  wakeIntervalMin;
    uint8_t  queueDepth;    // samples currently queued
    uint32_t rtcUnix;       // node RTC time at wake
} node_hello_message_t;
enum FwOtaState : uint8_t {
    FW_OTA_IDLE           = 0,  // no probation state / unknown
    FW_OTA_PENDING_VERIFY = 1,  // just-installed image on first-boot probation
    FW_OTA_CONFIRMED      = 2,  // valid / confirmed good
    FW_OTA_INVALID        = 3,  // marked invalid (rolled back)
    FW_OTA_ABORTED        = 4,  // aborted install
    FW_OTA_EMPTY          = 5,  // no readable image in the slot
};
typedef struct fw_caps_message {
    char     command[16];      // "FW_CAPS"
    char     nodeId[16];
    uint16_t protocolVersion;  // NODE_PROTOCOL_VERSION the node speaks
    char     fwVersion[12];    // running semantic version, e.g. "0.1.0"
    char     buildId[24];      // running git short hash (+ "-dirty")
    char     hwTarget[16];     // hardware target, e.g. "node-v3"
    uint32_t maxImageSize;     // inactive OTA slot capacity (bytes)
    uint8_t  rollbackCapable;  // 1 = deferred-verify rollback available
    uint8_t  reserved[3];      // (v1 payload ended here — 96 bytes)
    char     runningSlot[6];    // "app0" / "app1" (running slot label)
    uint8_t  runningOtaState;   // FwOtaState of the running slot
    uint8_t  otherSlotState;    // FwOtaState of the inactive slot
    char     otherVersion[12];  // inactive slot's app-desc version ("" if empty)
} fw_caps_message_t;
static_assert(sizeof(fw_caps_message_t) <= 250,
              "FW_CAPS exceeds the ESP-NOW v1 payload ceiling");
#define FW_CAPS_V1_BYTES 96
static_assert(offsetof(fw_caps_message_t, runningSlot) == FW_CAPS_V1_BYTES,
              "FW_CAPS v1 layout changed — update FW_CAPS_V1_BYTES / backend");
typedef struct node_status_message {
    char command[16];       // "NODE_STATUS"
    char nodeId[16];
    uint8_t state;          // 0=UNPAIRED, 1=PAIRED, 2=DEPLOYED
    uint8_t rtcSynced;      // 0/1
    uint8_t deployed;       // 0/1 (node local deployedFlag)
    uint8_t rescueMode;     // 0/1
    uint32_t rtcUnix;       // node RTC unix when status was generated
} node_status_message_t;
typedef struct config_snapshot_message {
    char     command[20];       // "CONFIG_SNAPSHOT"
    char     mothership_id[16];
    uint16_t configVersion;     // version being pushed
    uint8_t  wakeIntervalMin;
    uint16_t syncIntervalMin;
    uint32_t syncPhaseUnix;
    uint16_t sensorMask;
} config_snapshot_message_t;
typedef struct config_apply_ack_message {
    char    command[20];        // "CONFIG_ACK"
    char    nodeId[16];
    uint16_t appliedVersion;
    uint8_t ok;                 // 1 = applied OK, 0 = failed
} config_apply_ack_message_t;
#define NODE_PROTOCOL_VERSION 2
#define NODE_REQUIRE_DURABLE_SNAPSHOT_ACK 0
typedef struct snapshot_ack {
    char     command[16];       // "SNAPSHOT_ACK"
    char     nodeId[16];
    uint32_t seqNum;
    uint8_t  persisted;         // 1 = mothership durably stored this seq
    uint8_t  protocolVersion;   // NODE_PROTOCOL_VERSION
    uint16_t reserved;
} snapshot_ack_t;
typedef struct __attribute__((packed)) sync_session_open_message {
    char     command[16];       // "SYNC_SESSION"
    uint32_t sessionId;         // unique for this mothership wake
    uint16_t joinWindowMs;      // time allowed for jittered NODE_HELLO replies
    uint16_t sessionWindowSec;  // total bounded radio session
    char     mothership_id[16];
} sync_session_open_message_t;
typedef struct __attribute__((packed)) dump_grant_message {
    char     command[16];       // "DUMP_GRANT"
    char     nodeId[16];        // only this node may transmit snapshots
    uint32_t sessionId;
    uint16_t grantId;
    uint8_t  maxRecords;        // fairness quota for this round
    uint8_t  reserved;
    uint16_t grantWindowMs;     // node must stop before this expires
    uint16_t reserved2;
} dump_grant_message_t;
typedef struct __attribute__((packed)) dump_done_message {
    char     command[16];       // "DUMP_DONE"
    char     nodeId[16];
    uint32_t sessionId;
    uint16_t grantId;
    uint8_t  sentRecords;
    uint8_t  remainingRecords;
    uint8_t  status;            // 0=quota/empty, 1=send/ACK failure, 2=deadline
    uint8_t  reserved;
} dump_done_message_t;
typedef struct __attribute__((packed)) sync_release_message {
    char     command[16];       // "SYNC_RELEASE"
    char     nodeId[16];
    uint32_t sessionId;
    uint32_t mothershipUnix;    // final clock synchronization
    uint32_t syncPhaseUnix;     // active/new rendezvous phase
    uint16_t syncIntervalMin;   // active/new rendezvous interval
    uint8_t  legacyGraceCycles; // old rendezvous cycles still being serviced
    uint8_t  flags;             // bit0=schedule transition active
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

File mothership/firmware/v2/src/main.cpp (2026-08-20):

// Mothership V1 main firmware
// Wake-reason branching architecture with power gating, RTC alarm scheduling,
// ESP-NOW sync, SD logging, and config/service modes.
//
// Boot sequence:
//   1. Assert PWR_HOLD (GPIO26) — CRITICAL, must be first
//   2. Detect wake reason (config latch, RTC alarm, or USB)
//   3. Branch to appropriate handler
//   4. Re-arm RTC alarm before power-down
//   5. Release PWR_HOLD to power off

#include <Arduino.h>
#include <Wire.h>
#include <esp_now.h>
#include <esp_system.h>  // esp_reset_reason()
#include <Preferences.h>
#include <WiFi.h>

#include "system/pins.h"
#include "system/power.h"
#include "system/wake_reason.h"
#include "system/hardware_identity.h"
#include "time/rtc_alarm.h"
#include "comms/espnow_sync.h"
#include "storage/sd_logger.h"
#include "storage/flash_logger.h"
#include "config/node_registry.h"
#include "config/deployment_store.h"
#include "config/deployment_epoch.h"
#include "comms/espnow_config.h"
#include "config/config_server.h"
#include "config/transmission_settings.h"
#include "config/sim_settings.h"
#include "storage/upload_queue.h"
#include "storage/json_payload.h"
#include "comms/modem_driver.h"
#include "protocol.h"
#include "firmware_identity.h"  // role/version/build/hw identity (FW_GIT injected)
#include "ota/mothership_selfupdate.h"
#include "ota/mothership_ota_release_store.h"
#include "ota/mothership_ota_cloud_fetch.h"
#include "command_dispatcher.h"
#include "control/backend_command_ingest.h"
#include "control/node_config_control.h"

// Defer OTA image confirmation to our own first-boot self-test (see the call to
// mothershipOtaFirstBootCheck() below). Without this the Arduino core would
// auto-confirm a new image before we know it is healthy, defeating rollback.
extern "C" bool verifyRollbackLater() { return true; }

// Enlarge the Arduino loop task stack (default 8 KB). The sync-wake upload
// builds the full status+JSON payload (nodes[], modem diagnostics, transmission,
// etc.) while handleSyncWake's large frame — snapshot buffers, node-config
// vector, ACK array — is still live beneath it, which overflowed the 8 KB
// stack and reset the board mid-upload. 16 KB gives comfortable headroom
// (RAM usage is ~14%). Must be at global scope.
SET_LOOP_TASK_STACK_SIZE(16 * 1024);

// ---------------------------------------------------------------------------
// Configuration
// ---------------------------------------------------------------------------
#ifndef DEFAULT_SYNC_INTERVAL_MIN
#define DEFAULT_SYNC_INTERVAL_MIN 60
#endif
// Total sync-wake budget (ESP-NOW listen window + modem upload). Raised from
// 180 s so that when a node is missing and the ESP-NOW window runs its full
// 120 s, the modem still has ~180 s to power on, register and upload.
static constexpr uint32_t kSyncSessionLimitMs = 300000UL;  // 5 min

// ---------------------------------------------------------------------------
// Upload subsystem globals
// ---------------------------------------------------------------------------
UploadQueue uploadQueue;

// Project started — first-ever boot timestamp (set once in NVS, never
// overwritten).  Populated in setup() for dashboard/status reporting.
uint32_t g_projectStartedUnix = 0;

// Boot diagnostics — captured once in setup(), reported in status.diagnostics.
// g_resetReasonStr is the human-readable esp_reset_reason(); g_bootCount is a
// monotonic power-on counter persisted in NVS namespace "diag".
String   g_resetReasonStr = "UNKNOWN";
uint32_t g_bootCount = 0;

// gSyncIntervalMin is now owned by config_server.cpp (loaded from NVS in
// config mode).  In sync-wake mode it falls back to the compile-time default
// when config mode has not run yet (e.g. first boot).

// ---------------------------------------------------------------------------
// Forward declarations
// ---------------------------------------------------------------------------
void handleSyncWake();
void handleConfigWake();
void handleServiceWake();
void performModemUpload(const TransmissionSettings& txSettings, uint32_t sessionStartMs);

static BackendCommandApplyResult executeBackendNodeConfig(const Command& command) {
  const NodeConfigApplyResult applied = controlApplyNodeConfig(command);
  BackendCommandApplyResult result{};
  result.command = applied.command;
  result.durable = applied.durable;
  result.applied = applied.registryApplied;
  result.wireConfigVersion = applied.wireConfigVersion;
  return result;
}

static bool resolveBackendNodeConfig(const Command& requested,
                                     Command& resolved,
                                     CmdOutcome& rejection) {
  return controlResolveBackendNodeConfig(requested, resolved, rejection);
}

static BackendCommandApplyResult executeBackendRecordingInterval(
    const Command& command) {
  return configApplyBackendRecordingInterval(command);
}

// Stage a CMD_DEPLOY_RELEASE: register it with the dispatcher (CAS/idempotency +
// result/revision) and, on a fresh accept, persist the requested releaseId as
// the pending OTA intent. The actual fetch/verify/install runs later this wake
// (mothershipOtaCloudFetchAndInstall), driven from the check-in flow — never
// inside this executor, which must return promptly.
static BackendCommandApplyResult executeBackendDeployRelease(
    const Command& command) {
  BackendCommandApplyResult out{};
  const CommandResult r = dispatcherSubmit(command);
  out.command = r;
  out.wireConfigVersion = 0;
  if (r.outcome == OUT_ACCEPTED || r.outcome == OUT_REPLAY) {
    // (Re)stage the fetch intent on BOTH a fresh accept and a redelivery.
    // Rationale: on the first attempt dispatcherSubmit() durably records the
    // commandId before we stage the OTA intent, so if otaReleaseStoreSetPending()
    // fails transiently the fast-path returns PERSIST_FAILED and the cursor is
    // NOT advanced. The backend then redelivers the same commandId — but now
    // dispatcherSubmit() returns OUT_REPLAY, and if we skipped staging here the
    // OTA would be silently and permanently dropped (dispatcher/cursor report
    // success, yet nothing is ever staged). Re-staging is safe: the ingest skips
    // any command whose sequence is <= the durable cursor (backend_command_ingest.cpp
    // line ~524) BEFORE this executor runs, so a completed release (cursor already
    // advanced) never reaches here; and re-staging the same releaseId is
    // idempotent, with mothershipOtaVerifyManifest() short-circuiting via
    // FW_ALREADY_INSTALLED (before the image download) in the edge case where the
    // image is already installed. Mirrors controlApplyNodeConfig /
    // configApplyBackendRecordingInterval: side effects are re-derived from durable
    // command identity, not gated on a single dispatcherSubmit() call's outcome.
    const bool staged = otaReleaseStoreSetPending(command.releaseId);
    out.durable = staged;
    out.applied = staged;
  } else {
    // A durable terminal decision (INVALID / REVISION_CONFLICT). The dispatcher
    // result is already recorded; there is nothing to stage or retry.
    out.durable = true;
    out.applied = true;
  }
  return out;
}

static bool markControlConverged(const char* nodeId,
                                 uint16_t configVersion) {
  const bool nodeChanged =
      controlMarkNodeConfigConverged(nodeId, configVersion);
  const bool intervalChanged =
      configMarkRecordingIntervalNodeConverged(nodeId, configVersion);
  return nodeChanged || intervalChanged;
}

// Deployment outbox acknowledgement lives with the store now
// (deploymentIngestAckResponse, config/deployment_store.cpp) so the config
// server's manual-upload path shares it. It used to be a file-static here,
// which meant a UI-triggered upload sent events and then ignored the acks -
// the outbox never drained and every session resent the same events.

static BackendIngestResult ingestBackendResponse(const String& responseBody) {
  deploymentIngestAckResponse(responseBody);
  const uint32_t rtcBefore = getRTCTime();
  const bool rtcTrusted = rtcBefore >= 1704067200UL;
  Serial.printf("[CONTROL] HTTP response body bytes=%u\n",
                static_cast<unsigned>(responseBody.length()));
  const BackendIngestResult result = backendIngestUploadResponse(
      responseBody, rtcBefore, rtcTrusted, resolveBackendNodeConfig,
      executeBackendNodeConfig, executeBackendRecordingInterval,
      executeBackendDeployRelease);
  const uint32_t diagnosticUnix = result.serverTimeUnix >= 1704067200UL
      ? result.serverTimeUnix : rtcBefore;
  const bool diagnosticsDurable = backendControlRecordDiagnostics(
      result, responseBody.length(), diagnosticUnix);
  Serial.printf("[CONTROL] response=%s rejection=%s bytes=%u commands=%u processed=%u rejected=%u replayed=%u nextCursor=%lu initialRevision=%lu cursor=%lu diagnostics=%s\n",
                backendIngestStatusStr(result.status),
                backendIngestRejectionStr(result.rejection),
                static_cast<unsigned>(responseBody.length()),
                static_cast<unsigned>(result.commandCount),
                static_cast<unsigned>(result.processedCount),
                static_cast<unsigned>(result.rejectedCount),
                static_cast<unsigned>(result.replayedCount),
                static_cast<unsigned long>(result.responseNextCursor),
                static_cast<unsigned long>(result.initialStateRevision),
                static_cast<unsigned long>(result.persistedCursor),
                diagnosticsDurable ? "durable" : "FAILED");

  // The battery-backed DS3231 (set from the browser-UTC field in config mode)
  // is the sole UTC authority for the fleet's sync schedule. We deliberately DO
  // NOT let the backend response clock override it: the backend's serverTimeUnix
  // was observed carrying LOCAL wall time (not UTC), and adopting it dragged the
  // RTC +2h off true UTC and desynced every deployed node. serverTimeUnix is
  // still surfaced above for diagnostics only. Re-enable an RTC correction here
  // ONLY once the backend guarantees serverTimeUnix is true UTC epoch seconds.
  return result;
}

static void boundedRetryAndShutdown(const char* context) {
  constexpr int kMaxAttempts = 3;

  for (int attempt = 1; attempt <= kMaxAttempts; ++attempt) {
    Serial.printf("[RETRY] %s: attempt %d/%d\n", context, attempt, kMaxAttempts);

    Wire.begin(PIN_SDA, PIN_SCL);
    Wire.setClock(100000);
    delay(100);

    if (initRTC() != RTC_ABSENT && armRescueAlarm(DEFAULT_SYNC_INTERVAL_MIN)) {
      Serial.printf("[RETRY] %s: rescue alarm armed on attempt %d\n", context, attempt);
      Serial.println("[RETRY] Releasing PWR_HOLD - board will wake on rescue alarm");
      releasePwrHold();
      return;
    }

    delay(500);
  }

  Serial.printf("[RETRY] %s: all attempts failed - trying one final best-effort rescue alarm\n",
                context);
  Wire.begin(PIN_SDA, PIN_SCL);
  Wire.setClock(100000);
  delay(100);
  const RtcInitStatus rtcStatus = initRTC();
  const bool rescueArmed = armRescueAlarm(DEFAULT_SYNC_INTERVAL_MIN);
  Serial.printf("[RETRY] %s: final RTC init=%s rescue alarm=%s\n",
                context, rtcStatus == RTC_OK ? "ok" :
                         (rtcStatus == RTC_PRESENT_TIME_INVALID ? "TIME_INVALID" : "ABSENT"),
                rescueArmed ? "armed" : "FAILED");
  Serial.printf("[RETRY] %s: releasing PWR_HOLD as last resort\n", context);
  releasePwrHold();
}

// ---------------------------------------------------------------------------
// ESP-NOW snapshot processing (main task only)
// ---------------------------------------------------------------------------
static void sendSnapshotAck(const uint8_t* mac, const DecodedSnapshot& decoded, bool persisted) {
  if (!mac) return;

  snapshot_ack_t ack{};
  strncpy(ack.command, "SNAPSHOT_ACK", sizeof(ack.command) - 1);
  strncpy(ack.nodeId, decoded.nodeId, sizeof(ack.nodeId) - 1);
  ack.seqNum = decoded.seqNum;
  ack.persisted = persisted ? 1 : 0;
  ack.protocolVersion = decoded.protocolVersion;

  const bool sendResult = sendSnapshotAckNow(mac, ack);
  Serial.printf("[SNAP-ACK] %.15s seq=%lu persisted=%u proto=%u send=%s\n",
                ack.nodeId, static_cast<unsigned long>(ack.seqNum),
                static_cast<unsigned>(ack.persisted),
                (unsigned)ack.protocolVersion,
                sendResult ? "OK" : "FAIL");
}

void processSnapshot(const DecodedSnapshot& decoded, const uint8_t* mac) {
  if (!mac) return;

  char macStr[18];
  snprintf(macStr, sizeof(macStr), "%02X:%02X:%02X:%02X:%02X:%02X",
           mac[0], mac[1], mac[2], mac[3], mac[4], mac[5]);

  const float* batV = decoded.find(SENSOR_ID_BAT_V);
  const float* airT = decoded.find(SENSOR_ID_AIR_TEMP);
  const float* airH = decoded.find(SENSOR_ID_AIR_RH);
  Serial.printf("[SNAP] RX=%s nodeId=%.15s seq=%lu present=0x%04X proto=%u bat=%.2fV airT=%.1f airH=%.1f\n",
                macStr, decoded.nodeId, static_cast<unsigned long>(decoded.seqNum),
                (unsigned)decoded.sensorPresent, (unsigned)decoded.protocolVersion,
                batV ? *batV : 0.0f, airT ? *airT : 0.0f, airH ? *airH : 0.0f);

  // Stamp the deployment the sample was actually taken under, BEFORE it reaches
  // the CSV buffer — so a reading recorded before a redeploy but uploaded after
  // it keeps the old deployment. `decoded` is a const reference, so stamp a copy
  // rather than casting away const.
  DecodedSnapshot stamped = decoded;
  stamped.deploymentEpoch = resolveEpochForSample(stamped.nodeId, stamped.nodeTimestamp);

  bool persisted = false;
  if (flashIsReady()) {
    const bool flashSaved = logDecodedSnapshot(stamped);
    persisted = persisted || flashSaved;
    if (!flashSaved) {
      Serial.println("[SNAP] Flash logging failed");
    }
  }
  if (sdIsReady()) {
    String archiveRow;
    const bool sdSaved = formatDecodedSnapshotCSVRow(stamped, archiveRow) &&
                         sdLogCSVRow(archiveRow);
    persisted = persisted || sdSaved;
  }
  if (!persisted) {
    Serial.println("[SNAP] No storage accepted the snapshot");
  }
  sendSnapshotAck(mac, decoded, persisted);

  for (auto& n : registeredNodes) {
    if (strncmp(n.nodeId.c_str(), decoded.nodeId, 16) == 0 ||
        memcmp(n.mac, mac, 6) == 0) {
      // A received snapshot is the strongest possible evidence of contact, and
      // it must stamp the durable absolute time too — not just the millis-based
      // session value, which is worthless to the next boot.
      noteNodeContact(n);
      if (batV && !isnan(*batV)) {
        n.lastReportedBatV = *batV;
      }
      if (decoded.nodeTimestamp > 0 && decoded.nodeTimestamp > n.lastNodeTimestamp) {
        n.lastNodeTimestamp = decoded.nodeTimestamp;
      }
      // Configured-sensor fault detection. A configured sensor whose channel is
      // absent from this snapshot (node emits a reading only on a successful
      // read) faults after two consecutive misses, so a single transient read
      // doesn't flap the dashboard. expectedSensorMask holds capability bits only.
      {
        const uint16_t present  = decoded.sensorPresent;
        // Shared normalisation, so the cached mask, this comparison and the UI
        // can never drift into using different layouts for the same channel.
        const uint16_t expected = nodeNormalizeSensorMask(n.expectedSensorMask);
        const uint16_t missNow  = (uint16_t)(expected & ~present);
        n.sensorFaultMask   = (uint16_t)(missNow & n.sensorMissPrev);
        n.sensorMissPrev    = missNow;
        n.lastSensorPresent = present;
        if (n.sensorFaultMask) {
          Serial.printf("[SNAP] %.15s sensor fault mask=0x%04X (expected=0x%04X present=0x%04X)\n",
                        decoded.nodeId, (unsigned)n.sensorFaultMask,
                        (unsigned)expected, (unsigned)present);
        }
      }
      break;
    }
  }

  // A snapshot's configVersion is an existing-protocol convergence signal when
  // CONFIG_ACK was lost. Map it back to the retained dashboard/local command
  // without adding another radio message.
  if (decoded.configVersion > 0) {
    markControlConverged(decoded.nodeId, decoded.configVersion);
  }

  // Legacy sensor_data_message_t packets are intentionally ignored. All
  // deployed nodes send node_snapshot_t (V1) or node_snapshot_v2_t (V2).
}

struct ActiveSyncNode {
  uint8_t mac[6] = {0};
  char nodeId[16] = {0};
  uint8_t queueDepth = 0;
  uint8_t failedGrants = 0;
  bool released = false;
  bool releaseConfirmed = false;
};

struct LegacyRendezvousState {
  bool active = false;
  uint16_t intervalMin = 0;
  uint32_t phaseUnix = 0;
  uint8_t remainingCycles = 0;
};

static LegacyRendezvousState loadLegacyRendezvousState() {
  LegacyRendezvousState state{};
  Preferences prefs;
  if (!prefs.begin("sync_grace", true)) return state;
  state.active = prefs.getBool("active", false);
  state.intervalMin = prefs.getUShort("old_min", 0);
  state.phaseUnix = prefs.getULong("old_phase", 0);
  state.remainingCycles = prefs.getUChar("remaining", 0);
  prefs.end();
  if (state.intervalMin == 0 || state.phaseUnix < 1704067200UL ||
      state.remainingCycles == 0) {
    state = {};
  }
  return state;
}

static void saveLegacyRendezvousState(const LegacyRendezvousState& state) {
  Preferences prefs;
  if (!prefs.begin("sync_grace", false)) return;
  prefs.putBool("active", state.active && state.remainingCycles > 0);
  prefs.putUShort("old_min", state.intervalMin);
  prefs.putULong("old_phase", state.phaseUnix);
  prefs.putUChar("remaining", state.remainingCycles);
  prefs.end();
}

static bool wakeMatchesRendezvous(uint32_t nowUnix, uint16_t intervalMin,
                                  uint32_t phaseUnix) {
  if (intervalMin == 0 || phaseUnix == 0 || nowUnix < phaseUnix) return false;
  const uint32_t period = (uint32_t)intervalMin * 60UL;
  const uint32_t remainder = (nowUnix - phaseUnix) % period;
  return remainder <= 120UL || (period - remainder) <= 120UL;
}

static uint32_t nextRendezvousUnix(uint32_t nowUnix, uint16_t intervalMin,
                                   uint32_t phaseUnix) {
  if (intervalMin == 0) return UINT32_MAX;
  const uint32_t period = (uint32_t)intervalMin * 60UL;
  if (phaseUnix == 0) return nowUnix + period;
  if (nowUnix < phaseUnix) return phaseUnix;
  const uint32_t slots = (nowUnix - phaseUnix) / period;
  return phaseUnix + (slots + 1UL) * period;
}

static void drainAndPersistSnapshots() {
  EspNowSnapSlot slots[8];
  int drained = 0;
  do {
    drained = drainSnapQueue(slots, 8);
    for (int i = 0; i < drained; ++i) {
      processSnapshot(slots[i].snap, slots[i].mac);
    }
  } while (drained > 0);
}

static int findActiveSyncNode(const std::vector<ActiveSyncNode>& nodes,
                              const uint8_t* mac, const char* nodeId) {
  for (size_t i = 0; i < nodes.size(); ++i) {
    if ((mac && memcmp(nodes[i].mac, mac, 6) == 0) ||
        (nodeId && strncmp(nodes[i].nodeId, nodeId, sizeof(nodes[i].nodeId)) == 0)) {
      return (int)i;
    }
  }
  return -1;
}

// Re-establish a known node whose own NVS record is unavailable. Config version
// is intentionally zero: the following normal NODE_CONFIG burst must reapply
// the FieldHub's authoritative active/standby state and sensor mask instead of
// treating the recovery deploy as convergence.
static bool buildRecoveryDeploy(const NodeInfo& node, uint16_t activeSyncMin,
                                uint32_t activeSyncPhase,
                                deployment_command_t& deploy) {
  const uint32_t nowUnix = getRTCTime();
  if (nowUnix < 1704067200UL || activeSyncPhase < 1704067200UL) return false;

  const DateTime now(nowUnix);
  const NodeDesiredConfig desired = getDesiredConfig(node.nodeId.c_str());
  memset(&deploy, 0, sizeof(deploy));
  strncpy(deploy.command, "DEPLOY_NODE", sizeof(deploy.command) - 1);
  strncpy(deploy.nodeId, node.nodeId.c_str(), sizeof(deploy.nodeId) - 1);
  strncpy(deploy.mothership_id, "M001", sizeof(deploy.mothership_id) - 1);
  deploy.year = now.year();
  deploy.month = now.month();
  deploy.day = now.day();
  deploy.hour = now.hour();
  deploy.minute = now.minute();
  deploy.second = now.second();
  deploy.configVersion = 0;
  deploy.wakeIntervalMin = desired.wakeIntervalMin ? desired.wakeIntervalMin
      : (node.wakeIntervalMin ? node.wakeIntervalMin : DEFAULT_WAKE_INTERVAL_MINUTES);
  deploy.syncIntervalMin = activeSyncMin;
  deploy.syncPhaseUnix = activeSyncPhase;
  deploy.sensorMask = desired.sensorMask;  // 0 = auto; else SNAP_PRESENT_* + VALID
  deploy.deploymentEpoch = node.deploymentEpoch;
  return true;
}
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
void loop() {
  // If we reach here, releasePwrHold() didn't cut power.
  // This happens when USB/SW10 is still holding VSYS after flashing.
  // Just keep trying to release PWR_HOLD — the board will die when
  // the user flicks SW10 to remove USB power.
  static unsigned long lastRetry = 0;
  if (millis() - lastRetry > 2000) {
    Serial.println("[WAIT] Board still alive — flick SW10 to cut USB power.");
    digitalWrite(PIN_PWR_HOLD, LOW);
    lastRetry = millis();
  }
  delay(100);
}

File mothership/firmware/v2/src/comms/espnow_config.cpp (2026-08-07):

#include "comms/espnow_config.h"
#include "config/node_registry.h"
#include "config/deployment_epoch.h"
#include "time/rtc_alarm.h"
#include "storage/flash_logger.h"
#include "storage/sd_logger.h"
#include "system/pins.h"
#include <esp_now.h>
#include <WiFi.h>
#include <esp_wifi.h>
#include <freertos/FreeRTOS.h>

// Fleet sync phase anchor + persistence (defined in config_server.cpp). Used
// by deploySelectedNodes() so a fresh-erased mothership promotes the first
// deploy's phase to its own anchor, keeping the mothership and nodes on the
// same sync slot. See the deploy-phase fix in deploySelectedNodes().
extern unsigned long gLastSyncBroadcastUnix;
void saveSyncRuntimeGuardsToNVS();

// Config-mode ESP-NOW command layer for Mothership V1.
// Slim extract from production espnow_manager.cpp.

static const char* kDeviceId = "001";
static constexpr uint8_t kBroadcastAddr[6] = {0xFF, 0xFF, 0xFF, 0xFF, 0xFF, 0xFF};
static portMUX_TYPE gRecoveryMux = portMUX_INITIALIZER_UNLOCKED;
static bool gKnownNodeRecoveryPending = false;
static char gKnownNodeRecoveryId[16] = {};

// -----------------------------------------------------------------------------
// Helpers
// -----------------------------------------------------------------------------

static String macToStr(const uint8_t mac[6]) {
  char b[18];
  snprintf(b, sizeof(b), "%02X:%02X:%02X:%02X:%02X:%02X",
           mac[0], mac[1], mac[2], mac[3], mac[4], mac[5]);
  return String(b);
}

static bool shouldRecoverKnownDeployedNode(const NodeInfo& node) {
  if (node.state != DEPLOYED) return false;
  const NodeDesiredConfig desired = getDesiredConfig(node.nodeId.c_str());
  return desired.targetState != 0;  // Never override an explicit dashboard unpair.
}
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

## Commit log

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2026-04-16 feat: Enhance RTC management and synchronization in firmware
    - Implemented mutex locking for RTC access to prevent race conditions.
    - Added caching for last known good RTC time to improve reliability during access failures.
    - Updated RTC setup to include mutex initialization and error handling.
    - Enhanced time retrieval functions to utilize cached values when RTC access fails.
    - Introduced deployment acknowledgment message structure for improved communication between nodes and mothership.
    - Refactored ESP-NOW sending logic to include recovery mechanism for better resilience during transmission failures.
    - Documented firmware sync workflow and testing strategy to clarify operational models an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
    [main.cpp, protocol.h, rtc_manager.cpp]
2026-04-17 Refactor RTC time formatting to use DD-MM-YYYY HH:MM:SS format
    - Updated the RTC initialization log to display time in DD-MM-YYYY format.
    - Changed the format of the RTC time string returned by getRTCTimeString.
    - Modified the setRTCTime function to log the time in the new format.
    - Adjusted the RTC verification log to reflect the new time format.
    - Updated the resetRTCToDefault log to match the new formatting style.
    [main.cpp, rtc_manager.cpp]
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2026-04-19 feat: Enhance local queue handling and protocol structures
    - Added QF_DROPPED flag to local_queue for tracking dropped records.
    - Updated enqueue logic to set qualityFlags when dropping oldest records.
    - Modified protocol structures to use uint16_t for configVersion and related fields to prevent overflow.
    - Introduced new fields in deployment_command for immediate configuration application.
    - Ensured NODE_HELLO sends both unicast and broadcast to improve reliability.
    - Removed dead code and clarified persistence mechanisms in RTC_DATA_ATTR usage.
    - Implemented robust handling for queue flushing to prevent data loss during sync operations.
    [local_queue.cpp, main.cpp, protocol.h]
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2026-04-24 Refactor sync interval handling and enhance sensor data snapshotting
    - Automatically derive sync interval from wake interval, removing the need for manual sync interval settings.
    - Simplify NVS storage by eliminating sync interval persistence; now computed on-the-fly.
    - Update web UI to reflect auto-sync settings and remove obsolete sync interval configuration options.
    - Introduce a new node snapshot structure to encapsulate all sensor readings in a single packet, reducing ESP-NOW traffic.
    - Modify local queue management to handle node snapshots instead of individual sensor readings, improving efficiency.
    - Update CSV header format for wide-format logging of node data, accommodating new snap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
    [local_queue.cpp, main.cpp, protocol.h]
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2026-06-05 Add WiFi integrity testing functionality with UDP echo and scanning capabilities
    - Implemented a new test file `bringup_wifi_integrity.cpp` for WiFi diagnostics.
    - Added support for configuring AP SSID, password, channel, and UDP ports via preprocessor directives.
    - Included functionality to handle UDP echo requests and send beacons.
    - Implemented network scanning and statistics reporting.
    - Added serial command handling for immediate scan, resetting counters, and displaying help.
    [local_queue.cpp, main.cpp, protocol.h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]
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2026-06-12 Add low-voltage bring-up and RX baseline tests for Node V3
    - Implemented bringup_v3_low_voltage.cpp to verify 3V3, VREF, and filtered rails without enabling the 22V boost.
    - Added functionality to measure VREF settling time and print pin states.
    - Created bringup_v3_rx_baseline.cpp for RX chain validation with TX disabled, including noise floor measurement and mux direction checks.
    - Introduced tests for RX-disabled edge count, RX-enabled noise baseline, and custom noise baseline with user-defined parameters.
    - Enhanced menu options for user interaction and improved readability of output.
    [v3_ultrasonic_pins.h, v3_ultrasonic_safe.h]
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2026-06-19 Add config wake and RTC alarm functionality with shutdown support
    - Introduced a new environment for testing config wake functionality.
    - Implemented a shutdown feature in the config server, allowing the board to power off via a web UI button.
    - Enhanced the RTC alarm handling to support phase-aligned wake times.
    - Added validation checks for paired nodes during loading from NVS to prevent corruption.
    - Updated the main loop to handle early shutdown based on node activity.
    - Created a comprehensive test for the config wake and RTC alarm path, ensuring proper operation during power cycles.
    - Adjusted sync window duration to allow for multiple nodes to sync effectively.
    [main.cpp, pins.h]
2026-06-21 Mothership V1: modem bring-up tests, LTE upload subsystem, robustness fix plan
    Modem bring-up (all 5 tests passed on hardware, no antenna):
    - AT command suite: UART link, module identification, SIM detection,
    network status queries, power-cycle stress test
    - Shared modem_at_helper.h with rail/PWRKEY/AT/graceful-shutdown helpers
    - Results recorded in MOTHERSHIP_V1_BRINGUP_RESULTS_2026-06-19.md
    LTE upload subsystem (compiles, awaiting antenna for live test):
    - ModemDriver class: power on/off, network wait, HTTPS POST, state machine
    - UploadQueue: byte-offset cursor (no duplicate uploads), streaming purge,
    emergency purge at 80% flash usage
    - TransmissionSettings: NVS-stored webhook URL, t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
    [main.cpp, transmission_settings.cpp]
2026-06-22 Add bring-up tests for Mothership V1 firmware
    - Implemented alarm verification test to ensure RTC alarm functionality.
    - Added atomic purge recovery test to validate power-safe data handling.
    - Created ESP-NOW queue test to verify snapshot queuing and overflow behavior.
    - Developed flash write check test to confirm LittleFS append failure reporting.
    - Introduced NVS anchor test for dual-copy CRC-protected sync records.
    - Added rescue alarm test to validate boot rescue and normal schedule replacement.
    - Implemented RTC validity test to classify RTC status and ensure safety on unknown wake.
    - Created upload chunk test to verify bounded chunked upload payload construction.
    [main.cpp, transmission_settings.cpp]
2026-06-22 Add robustness fix prompts and initial test for ESP-NOW callback safety
    - Introduced NODE_ROBUSTNESS_FIX_PROMPTS.md with detailed implementation steps for enhancing node firmware robustness.
    - Added Stage 1 test (bringup_callback_safety.cpp) to verify that the ESP-NOW receive callback defers I2C/NVS operations to the main loop using pending-action flags.
    - The test simulates receiving a TIME_SYNC packet and checks for quick callback return, flag setting, and correct time synchronization application.
    [main.cpp]
2026-06-23 Add message dispatch and event queue handling for node firmware
    - Introduced message_dispatch.h to define IncomingMessageType enum and functions for classifying incoming messages and validating targets.
    - Implemented node_event_queue.cpp and node_event_queue.h to manage NodeEvent structures, including enqueueing and dequeueing events, and maintaining event counters.
    - Created node_config_store.cpp and node_config_store.h for persistent storage of node configuration, including validation and migration from legacy configurations.
    - Developed tests for the node configuration store and message dispatch, ensuring robustness and correctness of the event queue and configuration handling.
    - Added fu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
    [local_queue.cpp, main.cpp]
2026-06-23 Enhance flash logging and unpair command handling
    - Added appendFloat function to handle NaN values in float logging for flash_logger.cpp.
    - Improved initFlash function to automatically format LittleFS on mount failure.
    - Updated logSnapshotRow and logSnapshotBatch functions to use appendFloat for float fields.
    - Modified unpair_command structure in protocol.h to include nodeId for targeted unpairing.
    - Updated message_dispatch.cpp to validate unpair command targets.
    - Ensured proper null termination for unpair command fields in node_event_queue.cpp.
    - Optimized local_queue.cpp to use static buffers for legacy and queue blob operations.
    - Added tests in bringup_node_dispatch.cpp for unpair c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
    [espnow_config.cpp, local_queue.cpp, main.cpp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]
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2026-07-01 feat: Supabase JSON payload with status object + sync schedule handover fix
    - Add StatusContext to json_payload builder (batVoltage, flashUsage, fleet counts, schedule info)
    - Include status object in every POST to Supabase ingest endpoint
    - Update meta object with deviceId and uploadReason
    - Fix sync schedule transition: preserve old anchor, hand over via SET_SYNC_SCHED broadcast
    - Add broadcastSyncScheduleNow() to espnow_sync for sync-window schedule delivery
    - Add non-blocking discovery state machine with /api/live polling
    - Add schedule transition banner to config UI
    - Remove hardcoded API key from source (enter via Settings/QR instead)
    [main.cpp, transmission_settings.cpp]
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2026-07-05 Refactor ESP-NOW sync handling and enhance spectral metadata testing
    - Updated platformio.ini for mothership and node firmware to include new test environments and configurations.
    - Refactored espnow_sync.cpp to improve snapshot handling and maintain backward compatibility with V1 snapshots.
    - Enhanced the handling of CONFIG_ACK messages and improved the snapshot queue management.
    - Introduced computeNextCollectionIsoLocal function to accurately report the next upload time during schedule changes.
    - Removed deprecated processSnapshot wrapper for V1 compatibility in main.cpp.
    - Added a new test for AS7341 spectral metadata to ensure extended fields are read correctly.
    - Improved saturation fl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
    [main.cpp, sensors_par_as7343.cpp]
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2026-07-17 Add tests for command dispatcher, manifest verification, OTA installer, and OTA slots
    - Implemented `bringup_dispatcher.cpp` to validate command dispatcher functionality including revisioning, idempotent replay, and reboot persistence.
    - Created `bringup_manifest_verify.cpp` to test Ed25519 signature verification for firmware manifests, ensuring correct parsing and compatibility checks.
    - Developed `bringup_ota_installer.cpp` to demonstrate the shared streaming OTA installer, validating installation processes and rollback mechanisms.
    - Added `bringup_ota_slots.cpp` to prove OTA app-slot functionality and rollback behavior, including negative tests for corrupt images.
    - Introduced `fw_version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
    [partitions_ota.csv]
2026-07-18 Add backend command ingest and node config control functionality
    - Implemented backend command ingest handling in `backend_command_ingest.h` and `backend_command_ingest.cpp`, including command result structures and response parsing.
    - Developed node configuration control logic in `node_config_control.h` and `node_config_control.cpp`, allowing for command resolution and application of node configurations.
    - Created unit tests for backend command ingest in `test_backend_command_ingest.cpp`, covering various scenarios including command processing, error handling, and state persistence.
    - Added tests for node configuration control in `test_node_config_control.cpp`, validating convergence behavio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
    [espnow_config.cpp, main.cpp]
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2026-07-18 Add backend contract for OTA A/B firmware-slot reporting and corresponding tests
    - Introduced a new documentation file detailing the backend contract for the OTA A/B firmware-slot reporting, including changes to the mothership and node status payloads.
    - Added new fields to the `status.firmware` and `status.nodes[]` entries to report both active and next boot slots, along with their respective versions and states.
    - Implemented a new test file to validate the JSON shaping of the firmware slots, ensuring the correct structure and values are emitted by the firmware.
    - The tests cover various scenarios, including confirmed slots, empty slots, and the handling of single and multiple OTA slots.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
    [main.cpp, protocol.h]
2026-07-18 Implement hardware identity management and provisioning payload parsing
    - Introduced `hardware_identity` module for managing FieldHub's canonical identity.
    - Added functions for formatting MAC addresses, generating hardware codes, and creating registration URIs.
    - Implemented secure connection-key provisioning with versioned FM1 payloads.
    - Updated `transmission_settings.h` to use compile-time provisioning credentials.
    - Modified `main.cpp` to utilize the new hardware identity functions.
    - Added unit tests for hardware identity and provisioning payload parsing to ensure correctness and security.
    [main.cpp]
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2026-07-19 fix: harden cloud OTA (6 review findings) — download stall, silent drop, retry cap, otaReason
    Robustness + regression fixes on the cloud-triggered mothership OTA path,
    found reviewing deb5dee against main's working flow. All 7 affected build
    envs compile clean (mothership main + 4 test envs; node prod + manifest test).
    Finding 1 (HIGH, blocking) — cch_stream_reader.h: the HTTP head terminator
    scan looked at the last 4 *written* bytes, which freeze once head_ fills to
    kMaxHead=2048 — so a response whose headers exceed the buffer (plausible for
    Supabase Storage: CORS+Cache-Control+ETag+security headers) wedged the reader
    "in headers" forever and silently dropped the whole image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
    [main.cpp]
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2026-07-30 Add node test harness script for automated self-test and firmware flashing
    This script performs the following steps:
    1. Builds and flashes the self-test firmware to the specified serial port.
    2. Captures the serial output during the self-test and parses the results.
    3. Reports the results, including any failures or warnings.
    4. Gates the flashing of production firmware based on self-test results.
    5. Flashes the production firmware if all checks pass.
    6. Confirms that the production firmware is running by checking the boot log.
    Usage instructions and options for the script are included in the header comments.
    [main.cpp]
2026-07-31 feat: FieldHub-owned deployment epochs with a crash-safe durable store
    The hub now owns a per-node deployment counter, stamps it onto every
    reading at receive time, and ships a durable outbox of deployment
    records to the backend. This is what lets the same hardware move to a
    new site without joining two unrelated locations into one series.
    Store (deployment_store.cpp):
    - LittleFS, not NVS: the 20 KB NVS partition is already near capacity,
    and a set of Preferences::put* calls is not atomic as a group. The
    temp->rename->backup sequence gives a genuinely atomic commit, so an
    interrupted write resolves to the complete old or complete new
    record, never a mixture.
    Lifecycle (deployment_e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
    [espnow_config.cpp, main.cpp]
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2026-08-01 fix: derive the CSV schema banner instead of hardcoding 30
    The boot banner printed "CSV schema=30" from a string literal, so it kept
    claiming 30 after the schema moved to 31. That is wrong at precisely the
    moment it matters: during the 30 -> 31 rollout the boot log is what an
    operator reads to confirm the epoch-bearing schema is live, and it was
    reporting the old value on firmware that had already moved.
    Now derived from kCurrentCSVColumnCount.
    Cosmetic - log output only, no functional path reads it.
    [main.cpp]
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2026-08-01 fix: clear acked deployment events on the manual-upload path too
    The UI upload delivered the End event and the backend applied it -
    HTTP 200 {"deploymentEventAcks":["53798015-1"],...}
    - but the hub reported "1 queued, 1 remaining" and kept it.
    ingestDeploymentEventAcks() was a file-static in main.cpp, reached only
    from the scheduled-sync path. config_server.cpp has its own
    ingestBackendResponseFromUi(), which handles control commands and
    diagnostics but never touched the outbox. So a manual or pre-shutdown
    upload sent events, received the acknowledgements, and discarded them.
    Consequence is cumulative rather than immediate: the backend upsert is
    idempotent so resending is harmless, but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
    [main.cpp]
2026-08-01 fix: an ended deployment is not a paused node in the fleet count
    fleet.paused counted 'state == DEPLOYED && recordingPaused'. End
    deliberately leaves the node DEPLOYED and converges it to STANDBY, so an
    archived deployment satisfies both and was reported as paused - the
    dashboard health box showed '1 paused' for a site that had been ended,
    not paused.
    Same Pause/End conflation already fixed in the state chips, surfacing
    again in the fleet tallies. Excluded ended deployments from all three
    counters (the initial status build, the manual-upload status build, and
    the post-command recount).
    [main.cpp]
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2026-08-01 fix: never delete readings the backend did not store
    74 readings were destroyed on 2026-08-01. Two independent faults, both
    fixed here.
    1. buildJsonUpload could truncate silently.
    The readings array is built and then COPIED into body, so both exist at
    once and the peak is roughly double. The heap guard budgeted for a single
    copy at 600 B/reading, and body.reserve() was UNCHECKED. A 76-row batch
    passed the guard, failed to allocate its body, and Arduino String reports
    no error when a grow fails - so a 5,892 byte document claiming 76
    readings went out. Real 31-column rows measure ~780 B each; 51 of them
    had produced a 39,632 byte body minutes earlier.
    The guard now budgets both buffers at 8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
    [main.cpp]
2026-08-01 fix: bound the JSON build by actual chunk size, not the maxReadings ceiling
    The heap guard added in a57b3a0 was itself wrong. Budgeting
    maxReadings * 850 * 2 demands ~178 KB of free heap, but the caller bounds
    a chunk by CSV BYTES so 100 rows is a ceiling that is essentially never
    reached. On hardware with less than that free the build would be refused
    outright and the queue would wedge - trading data loss for a permanent
    stall, which is not an improvement.
    The estimate now comes from the chunk actually supplied. JSON runs ~4x
    the CSV it came from, measured on real uploads (6,419 -> 25,446 and
    11,099 -> 39,632), and the maxReadings figure is kept only as an upper
    bound.
    Also halves the chu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
    [main.cpp]
2026-08-01 fix(hub): un-strand undeliverable config versions and stop faking lastSeen
    Two defects found by comparing a hub sync log against node 3's serial on
    2026-08-01, both of which hid the other.
    A. Stranded desired state.
    Nodes apply a NODE_CONFIG only when its version is STRICTLY greater than
    the one they already hold. The hub was broadcasting
    NODE_CONFIG -> ENV_6C0A80 v12 target=2
    to a node holding cfgV=12 with paused=1, which it had taken from that
    same v12 carrying target=3. The node's gate rejects it, ACKs ok=1
    ("already current"), and stays paused; the hub reads that ACK as
    convergence and records recordingPaused=false. Both sides then report
    success forever while the node never resume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
    [main.cpp]
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2026-08-01 fix(node): wake a minute before the sync slot, not on it
    SYNC_PRE_WAKE_SEC was 0, so the node powered on exactly at its slot and
    then spent ~2.5s booting and enumerating 14 sensors before it could hear
    anything. The FieldHub wakes ~10s early and holds its rendezvous only to
    slot+15s, so the only overlap was the tail of the hub's window — every
    source of jitter (cold boot, an I2C retry, a slower sensor init, hub wake
    variance) ate directly into it. ENV_6C0A80 has the heaviest sensor load
    in the fleet and is the one that shows it.
    Alarm2 is minute-resolution, so 60s is the smallest lead that can be
    expressed at all; anything smaller is floored straight back onto the slot.
    This also require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
    [main.cpp]
2026-08-01 fix(node): refuse a stale TIME_SYNC that drags the clock backwards
    Root cause of ENV_6C0A80 going silent after being undeployed and
    redeployed on 2026-08-01.
    The FieldHub sends TIME_SYNC at the START of its rendezvous and
    SYNC_RELEASE at the END; both carry mothership time and both set the RTC.
    Events are queued and applied in loop context, so the older TIME_SYNC can
    be applied AFTER the newer release. Captured in the 19:37 window:
    [SYNC] RELEASE_ACK ... applied=1 -> RTC = 19:37:15
    TIME_SYNC applied, RTC set to 19:36:52
    Previous sync: 1785613035 (19:37:15)
    23 seconds backwards, which is the length of the hub's join window.
    That is self-locking. The node computes its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
    [main.cpp]
2026-08-05 fix(node): remove legacy sync fallback that could strand PWR_HOLD forever
    A rolling-upgrade fallback for mothership builds that only ever spoke the
    SYNC_WINDOW_OPEN marker protocol (never the full SYNC_SESSION_OPEN
    handshake) could lose a timing race against a fully modern mothership: the
    node would give up waiting at 2.5s and blind-flush its queue, then the real
    session-open would arrive moments later mid-flush and set
    g_syncSessionOpenPending with nothing left to clear it. hasCriticalPendingWork()
    then reported it forever, permanently blocking PWR_HOLD release -- observed
    live on two different field nodes as an infinite "release deferred" loop
    that only recovered with a manual power cycle.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
    [main.cpp]
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2026-08-06 chore: remove decommissioned mothership/firmware/v1 tree
    The v1 firmware and its bring-up tests were fully superseded by v2 and
    no longer referenced by any active build; keeping them around was pure
    repo clutter.
    [partitions.csv]
2026-08-06 fix(hub): root-cause deployment-epoch desync, persist sensor-fault state, gate soil probe presence
    Three fixes, all hardware-verified on COM4 (hub) + COM3 (node 2):
    - deploySelectedNodes() built DEPLOY_NODE's epoch from a RAM-only
    NodeInfo mirror instead of the deployment store. A node whose registry
    entry was freshly recreated (e.g. its own NODE_STATUS re-registering it
    mid-session) could get redeployed with epoch=0 while the Field UI still
    read the old slot as "Ended", even though the node was live and syncing
    normally. Now reads deploymentFindByNodeId() directly.
    - sensorFaultMask/sensorMissPrev/lastSensorPresent and lastSeenUnix were
    RAM-only or only written as a side effec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
    [espnow_config.cpp, main.cpp, protocol.h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]
2026-08-06 feat(hub): consolidate cloud connect flow, add cellular to provision wizard
    - Add cellular APN step to /provision connect flow (step 3 of 4)
    - Remove standalone Cellular section from Settings (meaningless pre-connection)
    - Remove duplicate 'Open the connect flow' button from FieldHub identity section
    - Remove 'Re-run full setup' from Settings bottom
    - Add collapsed Cellular settings to FieldMesh service section (post-connection SIM swaps)
    - Make QR code visible by default on provision Step 1 and setup wizard Step 1
    - Rework provision widget: clear two-way guidance up front (paste vs scan)
    - Update setup wizard Step 2 text to mention cellular coverage
    - Add sim_settings.h/.cpp (cellular APN N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
    [main.cpp, sim_settings.cpp, transmission_settings.cpp]
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

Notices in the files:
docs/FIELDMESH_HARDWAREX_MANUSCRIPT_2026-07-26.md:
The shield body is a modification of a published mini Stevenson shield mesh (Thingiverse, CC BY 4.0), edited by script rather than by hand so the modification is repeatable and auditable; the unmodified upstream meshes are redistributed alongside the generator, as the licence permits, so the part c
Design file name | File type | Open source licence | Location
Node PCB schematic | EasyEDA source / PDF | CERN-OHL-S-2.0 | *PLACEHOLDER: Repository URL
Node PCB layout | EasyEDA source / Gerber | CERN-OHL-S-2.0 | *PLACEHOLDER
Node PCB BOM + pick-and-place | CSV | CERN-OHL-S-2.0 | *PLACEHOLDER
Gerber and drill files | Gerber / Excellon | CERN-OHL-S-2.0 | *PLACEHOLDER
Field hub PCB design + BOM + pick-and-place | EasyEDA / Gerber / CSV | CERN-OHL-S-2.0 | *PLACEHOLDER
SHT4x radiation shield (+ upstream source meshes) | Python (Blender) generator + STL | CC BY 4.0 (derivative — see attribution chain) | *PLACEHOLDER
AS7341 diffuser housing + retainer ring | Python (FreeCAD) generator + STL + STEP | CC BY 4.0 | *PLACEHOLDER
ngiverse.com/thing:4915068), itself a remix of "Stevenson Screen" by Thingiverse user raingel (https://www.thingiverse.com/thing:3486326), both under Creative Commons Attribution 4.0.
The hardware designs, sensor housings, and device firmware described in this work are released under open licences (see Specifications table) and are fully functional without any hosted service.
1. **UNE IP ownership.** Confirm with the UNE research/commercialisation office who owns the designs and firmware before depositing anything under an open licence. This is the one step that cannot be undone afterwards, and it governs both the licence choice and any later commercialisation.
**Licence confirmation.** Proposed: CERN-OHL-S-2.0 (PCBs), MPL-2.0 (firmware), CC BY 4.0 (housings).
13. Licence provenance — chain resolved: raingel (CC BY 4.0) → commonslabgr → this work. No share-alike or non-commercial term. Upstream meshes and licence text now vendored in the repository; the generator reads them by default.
